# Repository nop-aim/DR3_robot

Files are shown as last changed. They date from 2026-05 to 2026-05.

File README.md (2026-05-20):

# 🦾 Robot DR3 — Tài Liệu Dự Án

> **Môn học:** Thực Tập Kỹ Thuật Robot  
> **GVHD:** PGS.TS Đặng Xuân Ba  
> **Sinh viên thực hiện:**
> - Nguyễn Ngọc Hiển — 22151079  
> - Hoàng Thái Bảo — 22151051  
> - Nguyễn Thị Tuyết Mai — 22151112  
> - Phạm Văn Hoàng Quân — 22151142  

---

## 📸 Hình Ảnh Sản Phẩm

| Bản vẽ 3D (SolidWorks) | Hoàn thành |
|:---:|:---:|
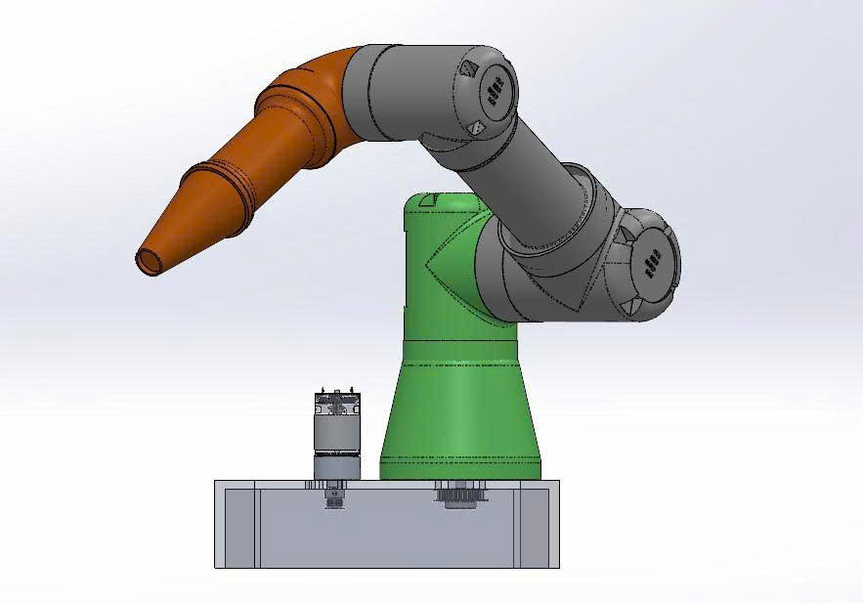
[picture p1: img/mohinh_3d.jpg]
3D Model
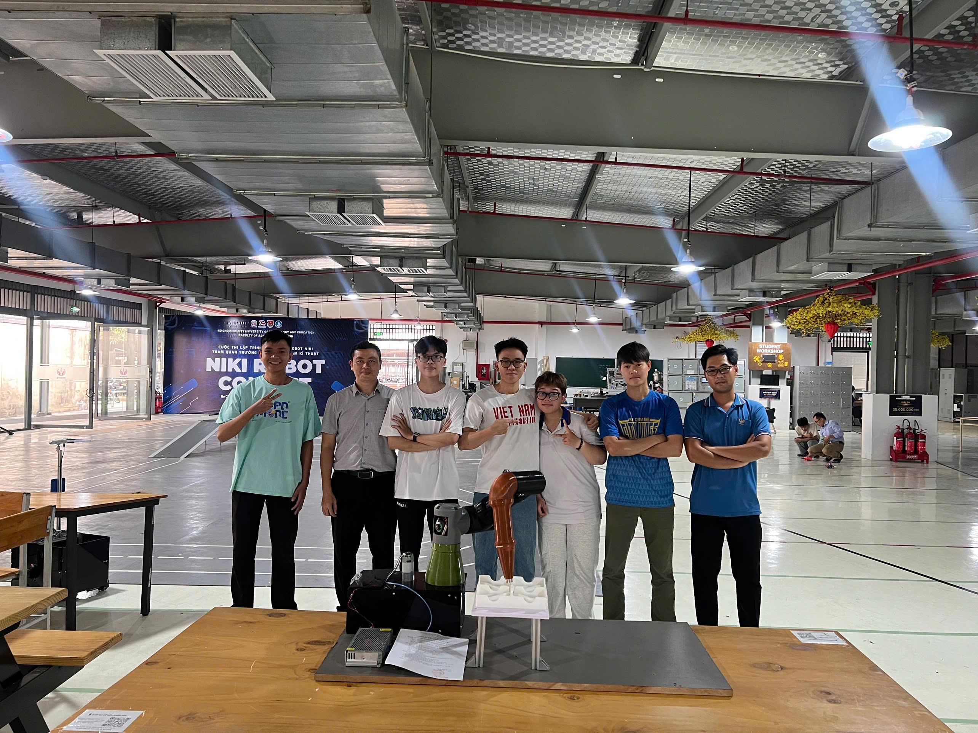
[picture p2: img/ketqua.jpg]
Team photo
|  |  |
| Robot 3-DOF: Base xanh + 2 link xám + EE cam | Nhóm cùng robot hoàn chỉnh|

---

## 📐 Thông Số Kỹ Thuật

| Thông số | Giá trị |
|---|---|
| Số bậc tự do | 3 (q1, q2, q3) |
| L1 — chiều cao từ base đến khớp 1 | 322 mm (142 + 180) |
| L2 — chiều dài link 2 | 275 mm |
| L3 — chiều dài link 3 / EE offset | 280 mm |
| d1 — offset ngang khớp 2 | 135 mm |
| d2 — offset ngang khớp 3 | 115 mm |
| Vi điều khiển | Arduino Mega 2560 |
| Baudrate PC ↔ Arduino | **115200** |
| Encoder M1 (khớp 1) | 16 PPR × 270 × (60/20) × 4 = **51840 xung/vòng** |
| Encoder M2 (khớp 2) | 16 PPR × 506 × 4 = **32384 xung/vòng** |
| Encoder M3 (khớp 3) | 11 PPR × 90 × 4 = **3960 xung/vòng** |
| Tọa độ lỗ thả (HOLE) | X=235, Y=−218, Z=240 mm |

---

## 🗂 Cấu Trúc Thư Mục

```
robot_dr3/
│
├── server_ui.py                  ← Entry point — khởi động toàn hệ thống
│
├── gui/
│   └── control_panel.py          ← Giao diện tkinter (StartPage + ControlPanel)
│
├── robot_controller/
│   └── robot_controller.py       ← Logic điều khiển, chạy trong thread riêng
│
├── kinematic/
│   ├── __init__.py
│   ├── DH_modify.py              ← Ma trận DH cải tiến
│   ├── forward_kinematics.py     ← Động học thuận
│   └── inv_kinematic.py          ← Động học nghịch (4 nghiệm)
│
├── com/
│   └── connect.py                ← Giao tiếp Serial (thread + queue)
│
├── arduino/
│   └── main.ino                  ← Firmware Arduino Mega
│
├── test_kinematic.py             ← Script test IK/FK qua terminal
└── requirements.txt
```

> ⚠️ **Quan trọng:** Import trong code dùng đường dẫn `from kinematic import ...` và `from com import connect as cn`. Phải **chạy từ thư mục gốc** `robot_dr3/`.

---

## ⚙️ Cài Đặt Môi Trường

### 1. Cài Python 3.9+

Tải tại [python.org](https://www.python.org/downloads/).  
Khi cài trên Windows: **tick "Add Python to PATH"**.

```bash
python --version   # Kiểm tra: Python 3.9.x trở lên
```

### 2. Tạo môi trường ảo (khuyến nghị)

```bash
python -m venv venv

# Windows
venv\Scripts\activate

# Linux / macOS
source venv/bin/activate
```

### 3. Cài thư viện

```bash
pip install numpy pyserial
```

`requirements.txt`:
```
numpy>=1.21.0
pyserial>=3.5
```

```bash
pip install -r requirements.txt
```

### 4. Cài Arduino IDE + Thư Viện Encoder

1. Tải [Arduino IDE 2.x](https://www.arduino.cc/en/software)
2. Mở **Library Manager** (`Ctrl+Shift+I`)
3. Tìm và cài: **`Encoder` by Paul Stoffregen**
4. Cắm Arduino Mega vào USB
5. Chọn **Board**: `Arduino Mega or Mega 2560`
6. Chọn đúng **Port** (ví dụ `COM6`)
7. Upload `arduino/main.ino`

---

## 🔌 Pinout Arduino Mega 2560

| Thành phần | Chân |
|---|---|
| Motor 1 — IN1 / IN2 / ENA | 14 / 15 / 4 |
| Encoder 1 — A / B | 3 (INT0) / 2 (INT1) |
| Motor 2 — IN1 / IN2 / ENA | 17 / 12 / 5 |
| Encoder 2 — A / B | 21 (INT5) / 20 (INT4) |
| Motor 3 — IN1 / IN2 / ENA | 11 / 10 / 9 |
| Encoder 3 — A / B | 18 (INT3) / 19 (INT2) |
| Van hút (Solenoid) — ENA | 7 |
| Cảm biến homing 1 / 2 / 3 | 46 / 44 / 42 |

---

## 🚀 Chạy Chương Trình

```bash
# Từ thư mục gốc robot_dr3/
python server_ui.py
```

Giao diện khởi động qua 2 bước:

**Màn hình StartPage** — hiện thông tin nhóm, nhấn **START** để vào bảng điều khiển.
<p align="center">
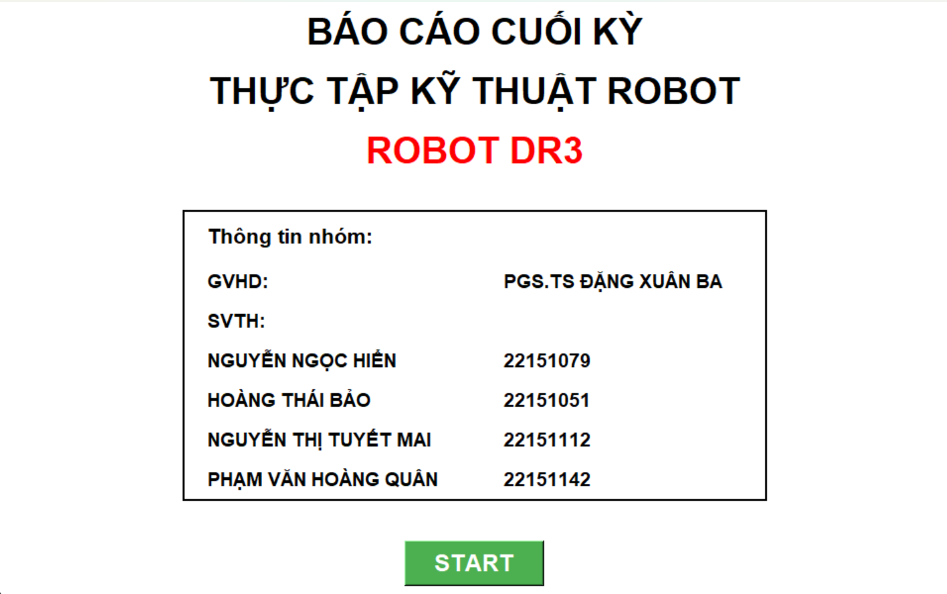
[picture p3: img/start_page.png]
  
</p>

**ControlPanel** — các nút điều khiển:
<p align="center">
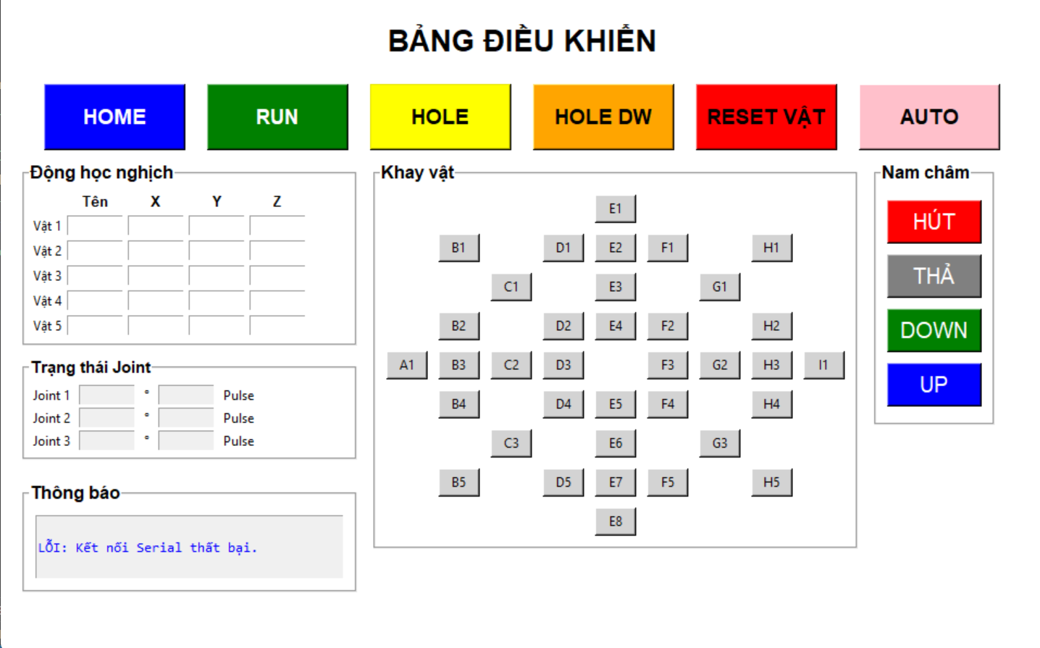
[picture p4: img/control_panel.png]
  
</p>

| Nút | Chức năng |
|---|---|
| **HOME** | Về vị trí gốc (chạy homing sequence) |
| **RUN** | Di chuyển tới tọa độ vật đang chọn (bay trên Z=240) |
| **HOLE** | Di chuyển tới vị trí lỗ thả (235, −218, 240) |
| **HOLE DW** | Hạ xuống lỗ thả (Z = 240 − 20 = 220) |
| **RESET VẬT** | Xóa toàn bộ danh sách vật đã chọn |
| **AUTO** | Tự động hút & thả toàn bộ vật đã chọn (tối đa 5) |

**Chọn vật từ khay:** Click vào ô lưới (A1, B1, C2 …) → tọa độ tự điền vào bảng "Vật 1 → 5".

---

## 🏗 Kiến Trúc Hệ Thống

```
┌──────────────────────────────────────────────────────────────┐
│                        server_ui.py                          │
│                                                              │
│   Main Thread (GUI)              Logic Thread (Robot)        │
│   ─────────────────              ──────────────────────      │
│                                                              │
│   StartPage (tkinter)            RobotController.run()       │
│        │                              │                      │
│        ▼                              ▼                      │
│   ControlPanel ──── cmd_queue ──► process_command()          │
│        ▲                │              │                     │
│        │                │         IK → Serial → wait DONE    │
│        └──── res_queue ◄┘              │                     │
│                                        ▼                     │
│                              connect.py (COM6, 115200)       │
│                                   │            ▲             │
│                              send_serial   reader_thread     │
│                                   │            │             │
│                                   ▼            │             │
│                            Arduino Mega 2560                 │
│                            (PID + S-Curve + Homing)          │
└──────────────────────────────────────────────────────────────┘
```

### Luồng Queue giữa GUI ↔ RobotController

```
GUI gửi lệnh:
  cmd_queue.put( ("SET",  (px, py, pz, idx)) )
  cmd_queue.put( ("HOLE", (px, py, pz, idx)) )
  cmd_queue.put( ("HOME", None) )
  cmd_queue.put( ("HUT",  None) )
  cmd_queue.put( ("THA",  None) )
  cmd_queue.put( ("QUIT", None) )

Robot phản hồi:
  res_queue.put( ("DONE",       (cmd_type, idx, angles)) )
  res_queue.put( ("IK_SUCCESS", (angles, pulses, idx))   )
  res_queue.put( ("IK_FAILED",  None)                    )
  res_queue.put( ("ERROR",      "message")               )
  res_queue.put( ("LOG",        "message")               )
```

ControlPanel gọi `self.after(100, self.check_logic_response)` để poll `res_queue` mỗi 100 ms — **không block GUI thread**.

---

## 🧮 Thuật Toán Động Học

### Ma Trận DH Cải Tiến (`DH_modify.py`)

$$
T_{i-1,i} =
\begin{bmatrix}
\cos\theta & -\sin\theta & 0 & a \\
\sin\theta\cos\alpha & \cos\theta\cos\alpha & -\sin\alpha & -\sin\alpha d \\
\sin\theta\sin\alpha & \cos\theta\sin\alpha & \cos\alpha & \cos\alpha d \\
0 & 0 & 0 & 1
\end{bmatrix}
$$

### Bảng Tham Số DH Robot DR3

$$
\begin{array}{|c|c|c|c|c|}
\hline
\textbf{Khớp} & \boldsymbol{\alpha\ (^\circ)} & \mathbf{a\ (mm)} & \boldsymbol{\theta} & \mathbf{d\ (mm)} \\
\hline
0 \rightarrow 1 & 0 & 0 & q_1 & L_1 = 322 \\
\hline
1 \rightarrow 2 & 90 & 0 & q_2 + 90^\circ & -d_1 = -135 \\
\hline
2 \rightarrow 3 & 0 & L_2 = 275 & q_3 & d_2 = 115 \\
\hline
3 \rightarrow EE & 0 & L_3 = 280 & 0 & 0 \\
\hline
\end{array}
$$

Động học thuận:
```python
T0_EE = T01 @ T12 @ T23 @ T3EE   # Ma trận 4×4
(Px, Py, Pz) = T0_EE[:3, 3]
```

### Động Học Nghịch (`inv_kinematic.py`)

```
Bước 1 — Tính w1 (2 ứng viên):
  r = √(Px² + Py²)
  α = atan2(Px, −Py)
  t = (d2 − d1) / r
  w1 = atan2(±√(1−t²), t) + α

Bước 2 — Với mỗi w1, tính w3 (2 nhánh ±s3):
  A = Px·cos(w1) + Py·sin(w1)
  B = Pz − L1
  c3 = (A² + B² − L2² − L3²) / (2·L2·L3)
  w3 = atan2(±√(1−c3²), c3)

Bước 3 — Tính w2:
  w2 = atan2(B, A) − atan2(L2 + L3·cos(w3), −L3·sin(w3))

→ Tối đa 4 nghiệm, loại trùng rồi chọn nghiệm có cả 3 góc ≤ 0
  (cấu hình elbow-up, phù hợp không gian làm việc thực tế)
```

---

## 🎮 Firmware Arduino — Điều Khiển PID Cascade

### Hai Vòng Lặp Độc Lập

| Vòng | Tần số | Nhiệm vụ |
|---|---|---|
| **Outer** — Position PID | 50 Hz (20 ms) | Sai số vị trí → lệnh vận tốc mong muốn |
| **Inner** — Velocity PID | 200 Hz (5 ms) | Bám vận tốc đặt → xuất PWM động cơ |

### Hệ Số PID (đã tinh chỉnh thực nghiệm)

| | Kp_pos | Ki_pos | Kd_pos | Kp_vel | Ki_vel | Kd_vel |
|---|---|---|---|---|---|---|
| Khớp 1 | 8.5 | 0.0 | 0.80 | 6.3 | 0.2 | 0.0 |
| Khớp 2 | 7.5 | 0.0 | 0.10 | 6.8 | 0.1 | 0.0 |
| Khớp 3 | 7.5 | 0.0 | 0.15 | 8.5 | 1.8 | 0.0 |

Ngoài ra có **Feedforward trọng trường** (`Kgrav`) và **Feedforward vận tốc/gia tốc** (`Kff_v`, `Kff_a`) cho khớp 2 và 3.

### Quỹ Đạo Quintic S-Curve

Hệ số đa thức bậc 5 đảm bảo vận tốc và gia tốc bằng 0 tại đầu/cuối:

```
p(t) = a₀ + a₁t + a₂t² + a₃t³ + a₄t⁴ + a₅t⁵

a₃ = 10·Δp / T³
a₄ = −15·Δp / T⁴
a₅ =   6·Δp / T⁵

T = max(2·|Δp| / MAX_VEL, MIN_TRAJ_TIME)
  với MAX_VELOCITY = 5000 xung/s, MIN_TRAJ_TIME = 1.5 s
```

### Tiêu Chí Kết Thúc Lệnh

Arduino chỉ gửi `"ALL DONE"` + `"DONE"` khi **đồng thời**:

- Quỹ đạo S-curve đã hoàn tất (`traj_active = false`)
- Sai số vị trí còn lại ≤ 3–7 xung
- Vận tốc hiện tại < 0.1–0.2 xung/ms
- Duy trì điều kiện trên liên tục **500 chu kỳ** (~2.5 s tại 200 Hz)
- Robot đã thực sự di chuyển (`has_moved = true`, encoder lệch > 5 xung)

---

## 📡 Giao Thức Lệnh Serial

| Lệnh | Cú pháp gửi | Arduino phản hồi |
|---|---|---|
| Di chuyển đến góc | `SET q1 q2 q3` (độ, float) | `DONE` và `ALL DONE` |
| Về HOME (homing) | `HOME` | `HOME DONE` |
| Bật van hút | `HUT` | `HUT DONE` |
| Tắt van hút | `THA` | `THA DONE` |

---

## 🔄 Luồng AUTO 

Luồng này sẽ gắp 5 vật liên tiếp, khi nhấn **AUTO**, `ControlPanel` tạo chuỗi lệnh cho mỗi vật như sau:

```
Cho mỗi vật i (i = 1..5):
  1. SET → (HOLE_X, HOLE_Y, HOLE_Z)      # Đến trên lỗ
  2. SET → (x_i, y_i, HOLE_Z)            # Đến trên vật (bay cao)
  3. HUT                                  # Bật hút
  4. SET → (x_i, y_i, z_i)              # Hạ xuống vật
  5. SET → (x_i, y_i, HOLE_Z)            # Nâng lên
  6. SET → (HOLE_X, HOLE_Y, HOLE_Z)      # Đến trên lỗ
  7. SET → (HOLE_X, HOLE_Y, HOLE_Z−20)   # Hạ vào lỗ
  8. THA                                  # Thả vật
```

Mỗi lệnh chỉ được gửi sau khi nhận `DONE` từ lệnh trước (xử lý trong `check_logic_response` với `self.after()`), tránh blocking GUI.

---

## 🧪 Test Động Học Qua Terminal

Dùng `test_kinematic.py` để kiểm tra IK/FK và giao tiếp Serial **không cần GUI**:

```bash
python test_kinematic.py
```

Nhập lệnh:
```
Nhập lệnh: 200 -150 300       # Nhập tọa độ Px Py Pz (mm)
Nhập lệnh: HOME
Nhập lệnh: HUT
Nhập lệnh: THA
Nhập lệnh: q                  # Thoát
```

Sau mỗi lệnh SET thành công, chương trình kiểm chứng lại bằng FK và in ra tọa độ Cartesian kết quả.

---

## ❗ Xử Lý Lỗi Thường Gặp

| Lỗi | Nguyên nhân | Giải pháp |
|---|---|---|
| `Không mở được serial` | Sai cổng hoặc chưa cắm USB | Sửa `SERIAL_PORT` trong `com/connect.py` |
| `ModuleNotFoundError: kinematic` | Chạy từ thư mục con | Chạy từ thư mục gốc `robot_dr3/` |
| `IK_FAILED` / không tìm được nghiệm | Tọa độ ngoài vùng làm việc | Kiểm tra (Px, Py, Pz) hợp lệ |
| Robot không gửi `DONE` | Queue bị nghẽn / timeout | Restart Python, kiểm tra baudrate = 115200 |
| Robot rung lắc | Kp quá cao | Giảm `Kp_pos` trong `main.ino` |
| Encoder sai chiều | Đảo A/B | Hoán đổi `ENC_A ↔ ENC_B` trong khai báo `Encoder enc_lib(B, A)` |
| HOME không dừng | Cảm biến homing không nhận | Kiểm tra chân 42 / 44 / 46, dây nối `INPUT_PULLUP` |

---

## 📄 Cấu Hình Nhanh

Chỉ cần sửa **một chỗ duy nhất** để thay đổi cổng Serial:

```python
# com/connect.py
SERIAL_PORT = "COM6"      # Windows: COM3, COM4, ...
# SERIAL_PORT = "/dev/ttyUSB0"    # Linux
# SERIAL_PORT = "/dev/tty.usbmodem14101"  # macOS
BAUDRATE = 115200
```

---

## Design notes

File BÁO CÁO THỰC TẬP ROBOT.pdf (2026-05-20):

BỘ GIÁO DỤC VÀ ĐÀO TẠO

TRƯỜNG ĐẠI HỌC SƯ PHẠM KỸ THUẬT TP.HCM

KHOA ĐIỆN – ĐIỆN TỬ

BỘ MÔN TỰ ĐỘNG ĐIỀU KHIỂN

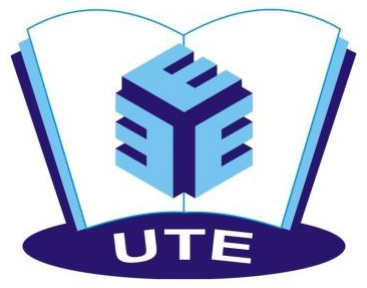
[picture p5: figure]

## BÁO CÁO CUỐI KỲ

## THỰC TẬP ROBOT

## CÁNH TAY ROBOT DR3 BA BẬC TỰ DO

GVHD: PGS.TS. Đặng Xuân Ba
SVTH: Nguyễn Ngọc Hiển | 22151079
Hoàng Thái Bảo | 22151051
Nguyễn Thị Tuyết Mai 22151112

Phạm Văn Hoàng Quân 22151142

TP. Hồ Chí Minh, tháng 12 năm 2025

i

LỜI CẢM ƠN

Chúng em xin chân thành gửi lời cảm ơn đến thầy Đặng Xuân Ba – người đã tận

tình hướng dẫn, định hướng và hỗ trợ chúng em trong suốt quá trình thực hiện đề tài. Sự

tận tâm và kiến thức chuyên môn sâu rộng của thầy không chỉ giúp em hoàn thành tốt

nội dung học thuật, mà còn truyền cảm hứng để em tiếp tục theo đuổi lĩnh vực điều

khiển và tự động hoá một cách nghiêm túc và bài bản.

Dù vẫn còn những thiếu sót nhất định, nhưng em hy vọng báo cáo này sẽ phản ánh

được nỗ lực học tập và nghiêm túc nghiên cứu của nhóm trong suốt học kỳ vừa qua.

ii

MỤC LỤC

iii

iv

DANH MỤC BẢNG BIỂU

v

DANH MỤC HÌNH ẢNH

CHƯƠNG 1. TỔNG QUAN

### 1.1. Đặt vấn đề

Cách mạng công nghiệp 4.0 đã thúc đẩy mạnh mẽ việc ứng dụng robot trong sản

xuất và đào tạo kỹ thuật. Robot công nghiệp ngày càng được sử dụng rộng rãi nhằm tự

động hóa các công việc lặp đi lặp lại, yêu cầu độ chính xác cao và nâng cao năng suất

lao động. Trong bối cảnh đó, việc tiếp cận và thực hành với các mô hình robot cơ bản

trong quá trình học tập có ý nghĩa quan trọng, giúp sinh viên nắm vững kiến thức nền

tảng về robot và điều khiển tự động.

Trong môn Thực tập Robot, robot cánh tay 3 bậc tự do (3 DOF) được sử dụng làm mô hình thực hành điển hình. Với cấu trúc đơn giản nhưng đầy đủ chức năng cơ bản,

robot 3 DOF có khả năng thực hiện các bài toán gắp và di chuyển vật thể trong không

gian, cụ thể là bài toán gắp bi. Thông qua bài toán này, sinh viên có thể hiểu rõ nguyên

lý chuyển động của các khớp, mối quan hệ giữa chuyển động khớp và vị trí đầu công

tác, cũng như cách phối hợp các trục để hoàn thành nhiệm vụ.

Để điều khiển chuyển động của robot, phương pháp điều khiển PID truyền thống

được áp dụng cho từng khớp. PID có ưu điểm là dễ cài đặt, dễ hiệu chỉnh và phù hợp

với các hệ thống robot đơn giản trong môi trường thực tập. Quá trình dò và điều chỉnh

các thông số PID giúp robot đạt được độ chính xác và ổn định cần thiết khi thực hiện

thao tác gắp bi.

Đề tài thực tập “Cánh tay robot DR3 ba bậc tự do” giúp sinh viên vận dụng kiến

thức lý thuyết vào thực tế, rèn luyện kỹ năng lập trình, điều khiển robot và đánh giá hiệu

quả vận hành của hệ thống, tạo nền tảng cho các môn học và ứng dụng nâng cao sau

này.

### 1.2. Mục tiêu

❖ Mục tiêu chung

Đề tài nhằm thiết kế và triển khai thành công mô hình robot cánh tay phục vụ học

tập và thực hành, có khả năng thực hiện bài toán gắp bi một cách ổn định và chính xác.

Thông qua quá trình thiết kế cơ khí, lắp ráp phần cứng và lập trình điều khiển, đề tài giúp sinh viên hiểu rõ nguyên lý hoạt động của robot công nghiệp và ứng dụng điều

khiển PID trong thực tế.

❖ Mục tiêu cụ thể

- Thiết kế mô hình robot cánh tay bằng phần mềm SolidWorks, bao gồm đầy đủ

các khớp chuyển động, tay gắp và kết cấu cơ khí phù hợp với yêu cầu gắp bi.

- Thực hiện lắp ráp và đi dây điện cho từng khớp động cơ, đảm bảo kết nối đúng

kỹ thuật, an toàn và hoạt động ổn định trong quá trình vận hành robot.

- Xây dựng và triển khai bộ điều khiển PID cho các động cơ tại các khớp, thông

qua việc dò và hiệu chỉnh tham số để đạt được chuyển động mượt và chính xác.

- Kiểm tra và đánh giá khả năng hoạt động của robot thông qua bài toán gắp và di

chuyển bi, đảm bảo robot thực hiện đúng quỹ đạo và yêu cầu đề ra.

- Góp phần củng cố kiến thức về robot, điều khiển tự động và kỹ năng thực hành,

làm nền tảng cho các môn học chuyên ngành và ứng dụng thực tế sau này.

### 1.3. Giới hạn đề tài

Giới hạn của đề tài được xác định nhằm đảm bảo phù hợp với mục tiêu học tập,

thời gian thực hiện và nguồn lực triển khai trong khuôn khổ môn Thực tập Robot. Cụ

thể, đề tài chỉ tập trung vào mô hình robot cánh tay có số bậc tự do hạn chế (robot 3 bậc

tự do) phục vụ cho bài toán gắp và di chuyển bi trong không gian làm việc đơn giản.

Các chuyển động của robot được xem xét chủ yếu ở mức cơ bản, không yêu cầu độ

chính xác cao như trong các ứng dụng công nghiệp phức tạp.

Về mặt điều khiển, đề tài chỉ sử dụng phương pháp điều khiển PID truyền thống,

được cài đặt trực tiếp trên vi điều khiển Arduino để điều khiển các động cơ tại các khớp

robot. Các phương pháp điều khiển nâng cao như điều khiển thích nghi, điều khiển tối

ưu, điều khiển mờ, hay các thuật toán học máy không được xem xét trong phạm vi đề

tài. Việc hiệu chỉnh PID được thực hiện theo phương pháp thử – sai (tuning thủ công) nhằm phục vụ mục tiêu học tập và thực hành.

Về mặt phần mềm, hệ thống được lập trình và giao tiếp thông qua Arduino và

Python, trong đó Arduino đảm nhiệm vai trò điều khiển phần cứng và Python được sử dụng để giao tiếp, gửi lệnh và quan sát trạng thái hoạt động của robot. Đề tài không triển

khai mô phỏng động lực học phức tạp trên các môi trường như MATLAB/Simulink, cũng không xây dựng mô hình toán học chi tiết của robot.

Ngoài ra, đề tài chưa xét đến các yếu tố ảnh hưởng phức tạp trong thực tế như ma

sát tại khớp, độ đàn hồi cơ khí, rung động, sai số cảm biến, nhiễu tín hiệu hay sự thay

đổi tải trọng trong quá trình gắp vật. Các vấn đề liên quan đến tối ưu hóa năng lượng,

an toàn vận hành nâng cao, hoặc ứng dụng robot trong môi trường công nghiệp thực tế

cũng không nằm trong phạm vi nghiên cứu của đề tài.

Do đó, kết quả đạt được chủ yếu mang tính thực hành và minh họa nguyên lý,

nhằm giúp sinh viên hiểu rõ cấu trúc, nguyên lý hoạt động và cách điều khiển cơ bản

của robot cánh tay, làm nền tảng cho các nghiên cứu và ứng dụng nâng cao trong tương

lai.

### 1.4. Nội dung nghiên cứu

Đề tài “Cánh tay robot DR3 ba bậc tự do” được xây dựng với các nội dung chính

sau:

− Chương 1: Tổng quan

− Chương 2: Cơ sở lý thuyết

− Chương 3: Thiết kế hệ thống

− Chương 4: Thiết kế thuật toán cho hệ thống

− Chương 5: Đánh giá trên thực nghiệm
− Chương 6: Kết luận

CHƯƠNG 2. CƠ SỞ LÝ THUYẾT

### 2.1. Tổng quan về Robot DR3

### 2.1.1. Giới thiệu chung

Robot DR3 trong đề tài này là một robot thuộc loại cánh tay máy nối tiếp (serial

manipulator). Đây là cấu trúc robot phổ biến nhất trong công nghiệp, được thiết kế mô

phỏng theo chức năng của cánh tay người. Robot bao gồm một chuỗi các khâu (links)

cứng được kết nối với nhau bằng các khớp (joints) động.

Loại robot này được ứng dụng rộng rãi trong nhiều lĩnh vực như lắp ráp, hàn, sơn,

và đặc biệt là các tác vụ gắp thả vật (pick-and-place) nhờ khả năng di chuyển linh hoạt

trong không gian làm việc của nó.

### 2.1.2. Cấu trúc Robor DR3 3 bậc tự do

Robot có 3 khớp quay chính, tạo nên 3 bậc tự do:

- Khớp 1 (Khớp đế): Cho phép toàn bộ cánh tay quay quanh trục thẳng đứng trên

đế.

- Khớp 2 (Khớp vai): Nâng/hạ cánh tay trên (khâu nối với đế).
- Khớp 3 (Khớp khuỷu): Gập/duỗi cánh tay dưới (khâu xa đế hơn).

Sự kết hợp chuyển động của 3 khớp này cho phép điểm cuối của robot (end-

effector) di chuyển đến các vị trí khác nhau trong không gian làm việc 3D.

### 2.1.3. Ưu nhược điểmm khi sử dụng Robot DR3 để gắp vật

❖ Ưu điểm:

- Không gian làm việc lớn: Robot có thể vươn tới các điểm xa và bao quát một

vùng làm việc rộng lớn xung quanh đế.

- Tính linh hoạt cao: Khả năng tiếp cận một vị trí từ nhiều hướng khác nhau, giúp

dễ dàng tránh vật cản.

- Cấu trúc đơn giản, dễ hiểu: Nguyên lý hoạt động và tính toán động học tương

đối trực quan, dễ tiếp cận cho mục đích học tập và nghiên cứu.

❖ Nhược điểm:

- Độ cứng vững thấp: Do cấu trúc dạng chuỗi hở, tải trọng và sai số bị tích lũy từ

gốc đến ngọn, làm giảm độ cứng vững, đặc biệt khi vươn xa.

- Tải trọng hạn chế: Các khớp phía gốc (như khớp vai) phải chịu mô-men lớn do

trọng lượng của toàn bộ các khâu phía sau và vật gắp.

- Tốc độ và gia tốc thấp hơn: Robot có khối lượng phần động lớn hơn, dẫn đến

quán tính lớn, làm hạn chế tốc độ và gia tốc tối đa.

### 2.2. Bộ điều khiển PID

Trong lĩnh vực điều khiển, bộ điều khiển PID (Proportional-Integral-Derivative)

là thuật toán phổ biến nhất nhờ tính hiệu quả và khả năng ứng dụng rộng rãi. Bộ điều

khiển này tính toán giá trị sai số $e(t)$ thông qua hiệu số giữa giá trị đo được (phản hồi)

và giá trị đặt mong muốn, từ đó điều chỉnh tín hiệu đầu ra để giảm thiểu sai số, giúp hệ

thống đạt được trạng thái ổn định.

Công thức tổng quát của bộ điều khiển PID:

0

( ) | ( ) | ( ) p | i | d

t
de u t | K e t | K e t dt K
dt
= | + | + ò
(2.1)

Trong đó:

- u(t): Tín hiệu điều khiển theo thời gian t.
- e(t): Sai số hệ thống theo thời gian t.
- Kp

, Ki và Kd

: Lần lượt là các hệ số tỉ lệ, tích phân và đạo hàm.

Việc hiệu chỉnh các thông số này sẽ thay đổi trực tiếp đặc tính của hệ thống:

- Kp

: Tác động đến tốc độ đáp ứng và sai số xác lập.

- Ki

: Giúp triệt tiêu sai số xác lập nhưng có thể gây vọt lố.

- Kd

: Giúp cải thiện độ ổn định và giảm độ vọt lố của hệ thống.

Bộ điều khiển PID nhận tín hiệu sai số từ cảm biến để tính toán và điều chế xung

PWM cấp cho các động cơ DC. Quá trình này diễn ra liên tục, đảm bảo các khớp của

cánh tay robot chuyển động chính xác đến vị trí mong muốn với độ sai lệch thấp nhất.

CHƯƠNG 3. THIẾT KẾ HỆ THỐNG

### 3.1. Giới thiệu tổng quan về hệ thống

### 3.1.1. Sơ đồ tổng quan hệ thống

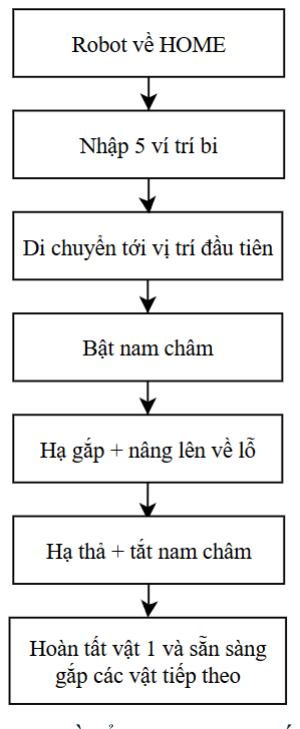
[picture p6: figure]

Hình 3.1. Sơ đồ tổng quan hệ thống gắp bi

### 3.1.2. Tính toán động học thuận, động học nghịch

3.1.2.1. Tính động học thuận cho Robot

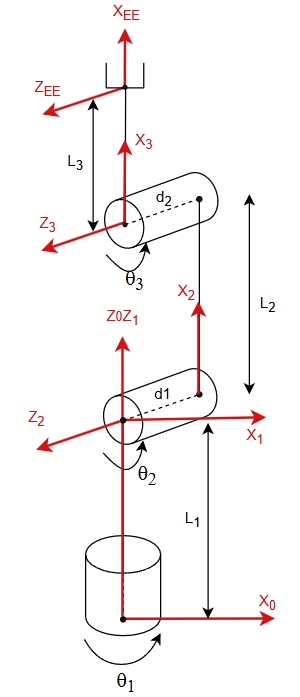
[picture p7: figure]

Hình 3.2. Đặt trục robot

❖ Bảng DH:

Bảng 3.1. Bảng DH

i | di | θi | ai-1 | αi-1
1 | l1 | q1 | 0 | 0
2 | -d1 | q2 + 90 | 0 | 90
3 | d2 | q3 | l2 | 0
4 | 0 | 0 | l3 | 0

❖ Tính toán các ma trận chuyển đổi:

Chuyển từ hệ {1} sang {0}:

| 1 | 1
0 | 1 | 1
1
1
| | 0 | 0
| | 0 | 0
0 | 0 | 1
0 | 0 | 0 | 1
c | s
s | c
T
l
é | ù −
ê | | ú
=
ê | | ú
ê | | ú
ê | ú ë | û

(3.1)

Chuyển từ hệ {2} sang {1}:

2 | 2
1 | 1
2
2 | 2
| | 0 | 0
0 | 0 | 1
| | 0 | 0
0 | 0 | 0 | 1
s | c
| | | d
T
c | s
é | ù − | −
ê | | ú −
=
ê | | ú
ê | | ú −
ê | ú ë | û

(3.2)

Chuyển từ hệ {3} sang {2}:

3 | 3 | 2
2 | 3 | 3
3
2

0
| | 0 | 0
0 | 0 | 1
0 | 0 | 0 | 1
c | s | l
s | c
T
| | d
é | ù −
ê | | ú
ê | ú =
ê | | ú
ê | ú ë | û

(3.3)

Chuyển từ hệ {EE} sang {3}:

3

3

1 | 0 | 0
0 | 1 | 0 | 0
0 0 | 1 | 0
0 0 | 0 | 1

EE

l

T

é | | ù
ê | | ú
= ê | | ú
ê | | ú
ê | ú ë | û

(3.4)

Ma trận chuyển đổi từ hệ trục tọa độ {EE} sang hệ trục tọa độ {0}:

1 23 | 1 23 | 1 | 2 1 2 | 3 1 23 | 1 1 | 2 1
0 | 1 23 | 1 23 | 1 | 2 1 2 | 3 1 23 | 1 1 | 2 1
23 | 23 | 1 | 2 2 | 3 23 0
0 | 0 | 0 | 1

EE

c s | c c | s | l c s | l c s | d s | d s
s s | s c | c | l s s | l s s | d c | d c
T
c | s | l | l c | l c
é | ù − | − | − | − | − | +
ê | ú − | − | − | − | − | + | − ê | ú =
ê | ú − | + | + ê | ú ë | û

(3.5)

Từ đó ta tìm được tọa độ điểm cuối của robot {EE} sang hệ trục tọa độ gốc {0}:

2 1 2 | 3 1 23 | 1 1 | 2 1
0
2 1 2 | 3 1 23 | 1 1 | 2 1
1 | 2 2 | 3 23

EE

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

(3.6)

3.1.2.2. Tính động học nghịch cho Robot

Ta có (3.5) tương đương với ma trận chuyển đổi đồng nhất như sau:

11 | 12 | 13
0 | 21 | 22 | 23
4
31 | 32 | 33
0 | 0 | 0 | 1

x

y

z

R | R | R | P
R | R | R | P
T
R | R | R | P
é | | | ù
ê | | | ú
ê | ú =
ê | | | ú
ê | ú ê | ú ë | û

(3.7)

Với:

P | l c s | l c s | d s | d s x
= − | − | − | + 2 1 2 | 3 1 23 | 1 1 | 2 1

(3.8)

P | l s s | l s s | d c | d c y
= − | − | + | − 2 1 2 | 3 1 23 | 1 1 | 2 1
(3.9)
P | l | l c | l c z
= + | + 1 | 2 2 | 3 23

(3.10)

- Tìm q1:

Ta lấy (3.8) nhân s1 và (3.9) nhân c1 ta được phương trình sau:

| | | 2 | 2
1 | 2 1 2 1 | 3 1 23 1 | 1 1 | 2 1
| | | 2 | 2
1 | 2 1 2 1 | 3 1 23 1 | 1 1 | 2 1

x

y

P s | l c s s | l c s s | d s | d s
P c | l s s c | l s s c | d c | d c
ìï | = − | − | − | +
í
ï | = − | − | + | − î

(3.11)

Trừ (3.11) theo vế ta thu được:

P s | P c | d | d x | y 1 | 1 | 2 | 1
− | = | −
(3.12)

Đưa công thức (3.12) về dạng
1 | 1 asin q | b | q | d ( ) | cos( ) + | = , khi đó:

2 | 2 | 2 | 2
tan 2 | , a | b
a
a | b | a | b

α

æ | ö
= | ç | ÷ è | ø + | +
(3.13)

Ta tìm được 2 nghiệm θ1 như sau:

2

1 | 2 | 2 | 2 | 2

2

1 | 2 | 2 | 2 | 2
tan 2 | 1 | ,
tan 2 | 1 | ,
d | | d
q | a
a | b | a | b
| d | | d
q | a
a | b | a | b

α

α

é | æ | ö ê = | − | + ç | ÷ ê
ç | ÷ è | ø ⁺ | +
ê
ê | æ | ö
ê
′ = | − | − | + ç | ÷
ê
ç | ÷ è | ø ⁺ | + ë

(3.14)

- Tìm θ3:

Ta lấy (3.8) nhân c1 và (3.9) nhân s1 ta được phương trình sau:

| 2 | | 2
1 | 2 1 | 2 | 3 1 | 23 | 1 1 1 | 2 1 1
| 2 | | 2
1 | 2 1 | 2 | 3 1 | 23 | 1 1 1 | 2 1 1

x

y

P c | l c s | l c s | d s c | d s c
P s | l s s | l s s | d c s | d c s
ìï | = − | − | − | +
í
ï | = − | − | + | − î

(3.15)

Cộng (3.15) theo vế ta thu được:

P c | P s | l s | l s x | y 1 | 1 | 2 2 | 3 23 + | = − | −
(3.16)

Kết hợp phương trình (3.10) và (3.16) ta được hệ phương trình sau:

1 | 1 | 2 2 | 3 23
1 | 2 2 | 3 23
x | y

z

P c | P s | l s | l s
P l | l c | l c
ìï | + | = − | −
í
ïî − = +

(3.17)

Đặt
1 | 1 | 1 , A P c | P s B P l = | + | = | −
x | y | z

, bình phương 2 vế của 2 phương trình trong công

thức (3.17), cộng vế theo vế ta được:

2 | 2 | 2 | 2 | 2 | 2 | 2 | 2 | 2 | 2
2 | 2 | 2 2 3 23 | 3 | 23 | 2 | 2 | 2 2 3 23 | 3 | 23 A | B | l s | l s l s | l s | l c | l c l c | l c + | = | + | + | + | + | + 2 | 2
(3.18)
2 | 2 | 2 | 2
2 | 3 | 2 3 3 A | B | l | l | l l c + | − | − | = 2
(3.19)

Đặt

2 | 2 | 2 | 2 C A | B | l | l = | + | − | − 2 | 3
, ta tìm được c3
:

3
23 2

C
c
ll

=
(3.20)

2
3 | 3 s | c = ± | −1
(3.21)

Ta tìm được 2 nghiệm θ3 như sau:

10 ( | )
( | )
3 | 3 | 3
3 | 3 | 3
tan 2 | ,
tan 2 | ,
q | a | s c
q | a | s c

é=
ê
ê ′
= | − ë

(3.22)

- Tìm θ2:

Từ phương trình (3.17), tách

23 23 cs,
theo công thức lượng giác ta được:
2 2 | 3 | 2 3 | 2 3 | 2 | 3 3 | 2 | 2 | 3 3
2 2 | 3 | 2 3 | 2 3 | 2 | 3 3 | 2 | 2 | 3 3
( | ) | ( | ) | ( | )
( | ) | ( | ) | ( | )
A | l s | l s c | c s | A c | l s | s l | l c
B l c | l c c | s s | B s | l s | c l | l c
ì | ì = − | − | + | = | − | − | + í | í Û
î | î = | + | − | = | − | + | +

(3.23)

Từ phương trình (3.23), ta được:

2 | 2 | 3 3
2
| 33
2 | 2 | 3 3
2
| 33
( | )
( | )
A s l | l c
c
ls
B c l l c
s
ls
ì | + | +
= ï
ï | −
í
− | + ï =
ïî | −

(3.24)

Thay thế s2 và c2
lẫn nhau ở 2 phương trình, ta thu được:
2 | 2 | 3 3
2 | 3 3
| 33
2
33
2 | 2 | 3 3
2 | 3 3
| 33
2
33
( | ) ( | )
( | ) ( | )
B c l | l c A | l | l c
ls
c
ls
A s l | l c B | l | l c
ls
s
ls
ì | − | +
+ | + ï | −
ï =
ï | −
í
+ | + ï | − | + ï | −

ï =
î | −

(3.25)

[ | ]
( | )
[ | ]
( | )
3 3 | 2 | 3 3 | 2 | 2 | 3 3
2 | 2
| | 33
3 3 | 2 | 3 3 | 2 | 2 | 3 3
2 | 2
| | 33
( | ) ( | ) | ( | )
( | ) ( | ) | ( | )
A l s | l | l c | B c l | l c
c
| | ls
B l s | l | l c | A s l | l c
s
| | ls
ì | − | + | + | − | +
ï =
ï
í
− | − | + | + | + ï
=
ï
î

(3.26)

Từ phương trình (3.26), ta tìm được θ2:

q | a | s c 2 | 2 | 2
= tan 2 | , ( | )
(3.27)

Như vậy, ta đã tìm được các góc q thông qua vị trí của End effector

T
P | P | P | P
x | y | z
= é | ù ë | û

( | )
( | )
( | )

2

1 | 2 | 2 2 | 2

2

1 | 2 | 2 2 | 2
2 | 2 | 2
3 | 3 | 3
3 | 3 | 3
tan 2 | , 1
tan 2 | , | 1
tan 2 | ,
tan 2 | ,
tan 2 | ,
d | d
q | a
a | b | a | b
d | d
q | a
a | b | a | b
q | a | s c
q | a | s c
q | a | s c

α

α

ìé | æ | ö ïê = | − | − ç | ÷ ïê | + | +
è | ø ïê
ïê | æ | ö
ïê
′ = | − | − | − ç | ÷
+ | + ïêë | è | ø ï
í =
ï
é= ï
ê ï
ê ′ = − ïë
ï
ï
ï
î

(3.28)

### 3.2. Thiết kế cơ khí

### 3.2.1. Thiết kế 3D trên phần mềm Solidworks

❖ Đế robot

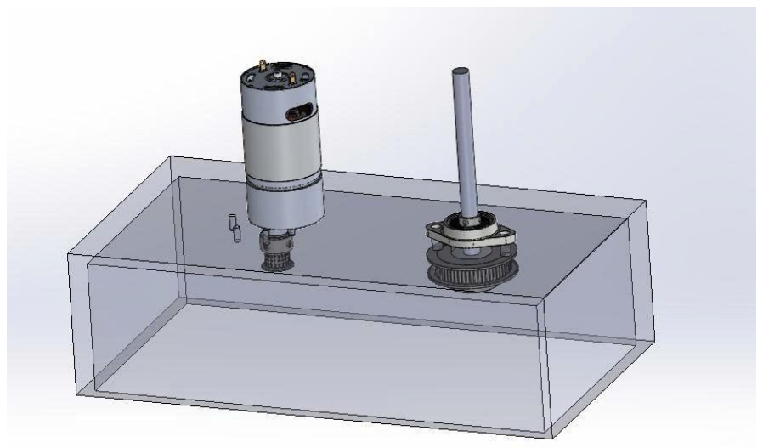
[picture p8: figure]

Hình 3.3. Hình ảnh 3D đế robot

❖ Khớp 1

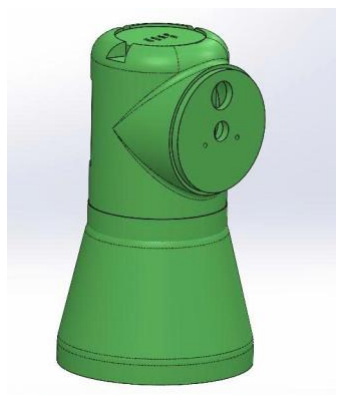
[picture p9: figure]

Hình 3.4. Hình ảnh 3D khớp 1

❖ Khớp 2

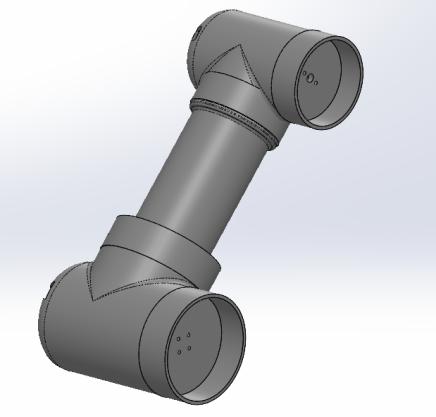
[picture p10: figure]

Hình 3.5. Hình ảnh 3D khớp 2

❖ Khớp 3

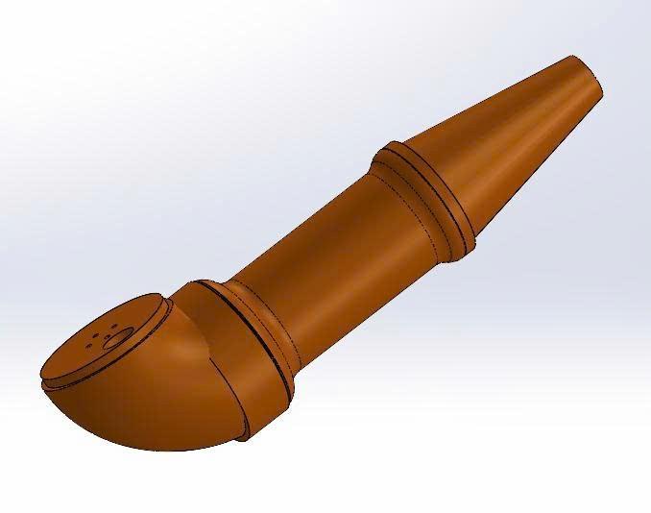
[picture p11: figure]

Hình 3.6. Hình ảnh 3D khớp 3

❖ Bản vẽ Robot hoàn thiện

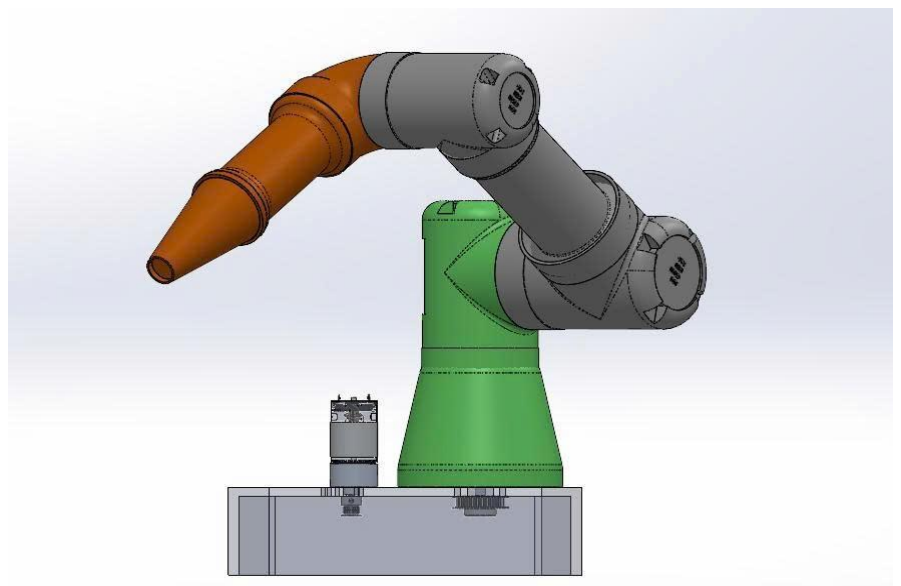
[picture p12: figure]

Hình 3.7. Hình ảnh 3D mô hình robot hoàn thiện

### 3.2.2. Lựa chọn thiết bị phần cứng

❖ Arduino Mega 2560 Pro

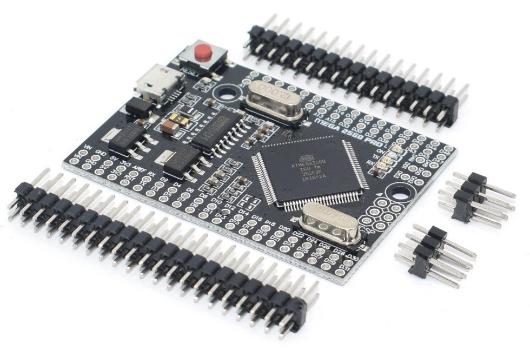
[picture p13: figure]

Hình 3.8. Arduino Mega 2560 Pro

Thông số kỹ thuật:

- Vi điều khiển chính: ATmega2560
- Tốc độ thạch anh: 16Mhz
- Nguồn nuôi mạch:
- 5VDC từ cổng Micro USB.
- Nguồn ngoài từ chân Vin từ 6~9VDC.
- Dòng đầu ra chân 5VDC khi cấp nguồn từ:
- Cổng USB: 500mA
- Chân Vin: 800mA
- Tích hợp IC chuyển nguồn 3.3VDC 800mA.
- Số chân Digital: 54 (hỗ trợ 15 chân PWM)
- Số chân Analog: 16
- Dòng ra tối đa trên GPIO: 20mA
- Dung lượng bộ nhớ Flash: 256 KB, 8 KB used by bootloader.
- SRAM: 8 KB
- EEPROM: 4 KB
- Kích thước: 38 x 55mm

❖ Động cơ Encoder JGB37-545 24V 46RPM

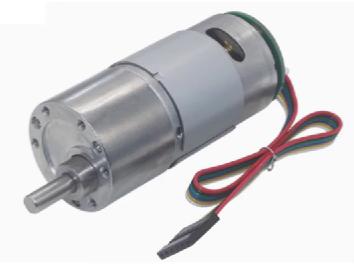
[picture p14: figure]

Hình 3.9. Động cơ Encoder JGB37-545 24V 46RPM

Thông số kĩ thuật:

- Mode: JGB37-545
- Tốc độ quay: 46 rpm
- Mô-men: 3.43 N.m
- Tỉ số truyền: 1:270
- Số xung / vòng: 16
- Điện áp cấp cho động cơ hoạt động: 24VDC
- Đường kính động cơ: 37mm
- Đường kính trục: 6mm

❖ Động cơ Encoder JGB37-545 24V 26RPM

Hình 3.10. Động cơ Encoder JGB37-545 24V 24RPM

Thông số kỹ thuật:

- Mode: JGB37-545
- Tốc độ quay: 24 rpm
- Mô-men: 3.43 N.m
- Tỉ số truyền: 1:506
- Số xung / vòng: 16
- Điện áp cấp cho động cơ hoạt động: 24VDC
- Đường kính động cơ: 37mm
- Đường kính trục: 6mm

❖ Động cơ Encoder JGB37-520 12V 111RPM

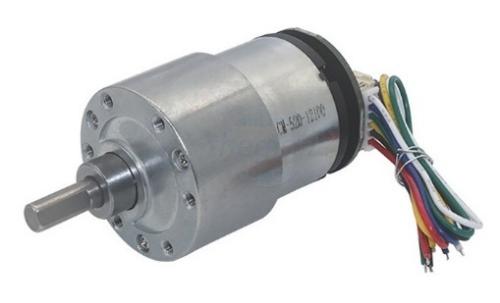
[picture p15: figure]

Hình 3.11. Động cơ Encoder JGB37-520 12V 111RPM

Thông số kĩ thuật:

- Mode: JGB37-520
- Tốc độ quay: 111 rpm
- Mô-men tối đa: 1.47 N.m
- Tỉ số truyền: 1:90
- Số xung / vòng: 11
- Điện áp cấp cho động cơ hoạt động: 12VDC
- Đường kính trục: 6mm
- Đường kính động cơ: 37mm

❖ Module điều khiển động cơ L298N

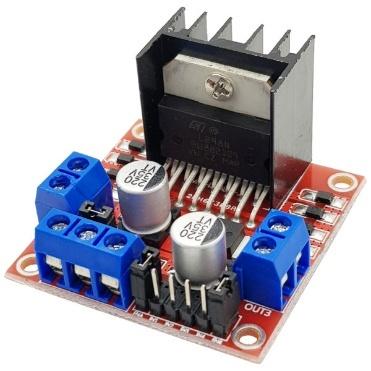
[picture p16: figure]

Hình 3.12. Module điều khiển động cơ L298N

Thông số kỹ thuật:

- Điện áp hoạt động: 5~30VDC
- Công suất tối đa: 25W 1 cầu
- Dòng tối đa cho mỗi cầu H là: 2A
- Mức điện áp logic: Low -0.3V~1.5V, High: 2.3V~Vss
- Kích thước: 43x43x27mm

❖ Module điều khiển động cơ BTS7960 43A

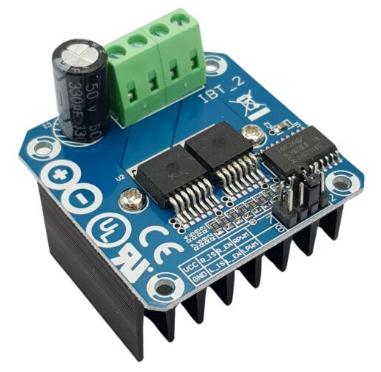
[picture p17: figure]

Hình 3.13. Module điều khiển động cơ BTS7960 43A

Thông số kỹ thuật:

- Nguồn cấp: 6 ~ 27VDC
- Dòng điện tải mạch: 43A (Tải trở) hoặc 15A (Tải cảm)
- Tín hiệu logic điều khiển: 3.3 ~ 5VDC.
- Tần số điều khiển tối đa: 25KHz.
- Bảo vệ quá nhiệt: BTS7960 bảo vệ chống quá nhiệt bằng cảm biến nhiệt tích hợp

bên trong.

- Kích thước: 40 x 50 x12mm.

❖ Mạch giảm áp Buck DC-DC XL4016E1 8A

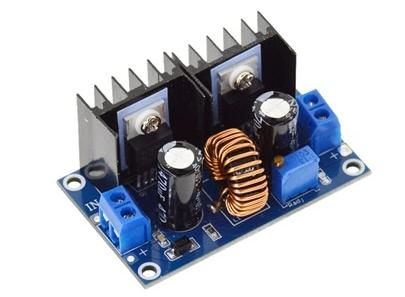
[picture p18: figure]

Hình 3.14. Mạch giảm áp Buck DC-DC XL4016E1 8A

Thông số kĩ thuật:

- Điện áp đầu vào: DC4-40V
- Điện áp đầu ra: DC1.25-36V
- Công suất tối đa: 200W
- Dòng điện ra: max 8A (hoạt động lâu dài, đề nghị 5A)

- Hiệu suất chuyển đổi: 94%
- Kích thước: 61x40x29 mm

❖ Module 1 Relay 12V Kích Mức Cao/Thấp

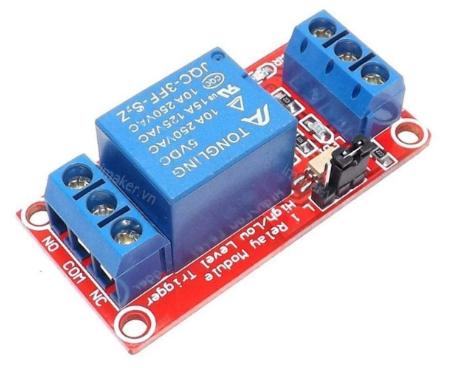
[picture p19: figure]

Hình 3.15. Module 1 Relay 12V Kích Mức Cao/Thấp

Thông số kỹ thuật:

- Nguồn cấp: 12VDC.
- Relay tiêu thụ dòng khoảng 80mA.
- Điện thế đóng ngắt tối đa: AC250V ~ 10A hoặc DC30V ~ 10A.
- Có đèn báo đóng ngắt trên mỗi Relay.
- Có thể chọn mức tín hiệu kích 0 hoặc 1 qua jumper.
- Kích thước: 5.0x2.6x1.9 cm

❖ Nam châm điện

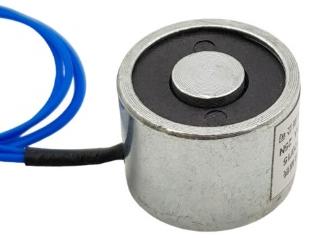
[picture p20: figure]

Hình 3.16. Nam châm điện

Thông số kỹ thuật:

- Điện áp cấp: 12VDC
- Dòng tiêu thụ: 0.25A
- Công suất: 3W
- Lực hút: 25N (~2.5kg)
- Đường kính: 20mm

- Lõi sắt: 8mm
- Độ dày: 15mm
- Nhiệt độ hoạt động tối đa 130°C
- Trọng lượng: 25g

❖ Công tắc hành trình

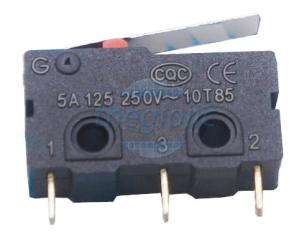
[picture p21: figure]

Hình 3.17. Công tắc hành trình

Thông số kĩ thuật:

- Loại: cần lẫy
- Cách gắn: hàn
- Dòng định mức: 5A
- Điện áp AC max: 250 VAC
- Vật liệu tiếp điểm: hợp kim bạc
- Tuổi thọ: 3.000.000 lần
- Nhiệt độ hoạt động: -25 → +85°C

❖ Khớp nối trục động cơ mặt bích

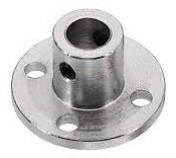
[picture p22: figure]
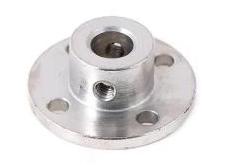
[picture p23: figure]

Hình 3.18. Khớp nối trục động cơ mặt bích 6mm và 8mm

❖ Puly GT2, bước răng 2mm

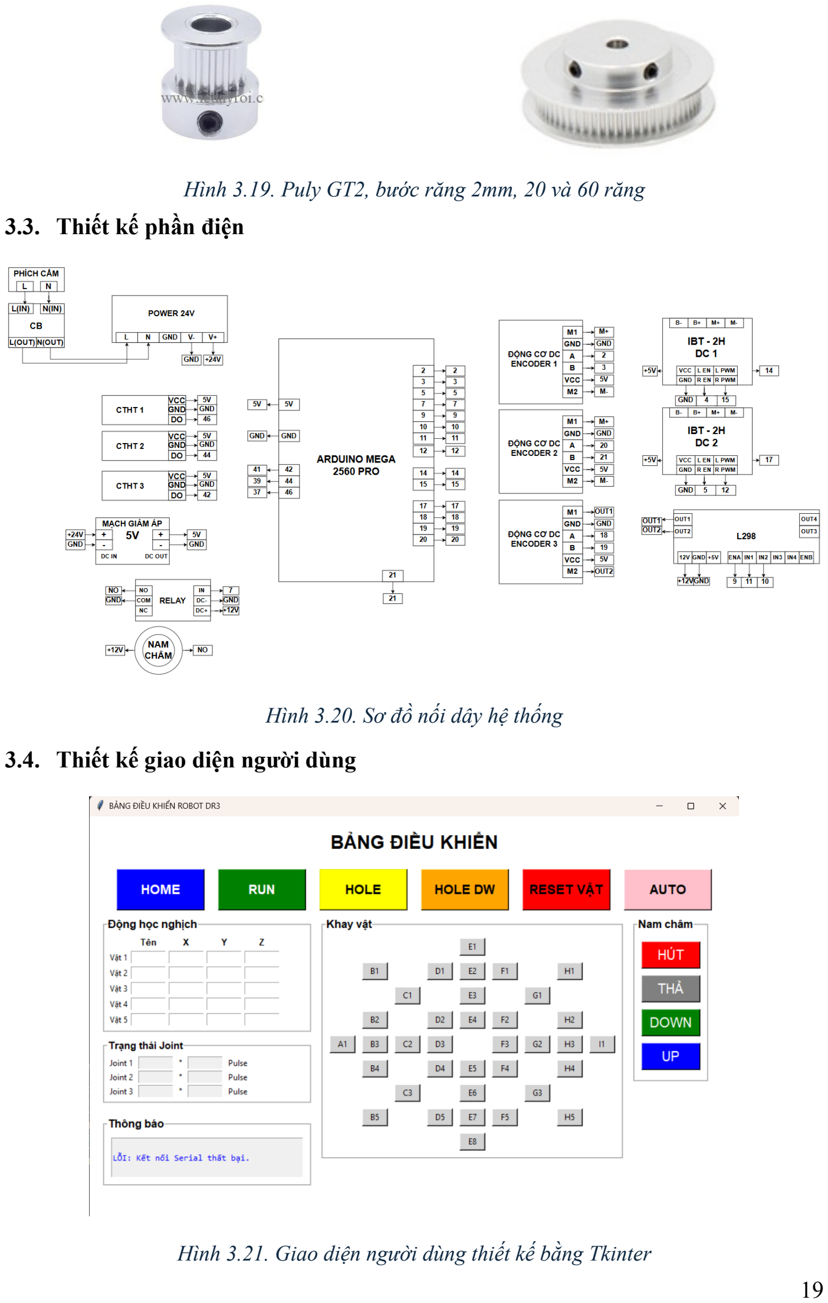
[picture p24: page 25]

Hình 3.19. Puly GT2, bước răng 2mm, 20 và 60 răng

### 3.3. Thiết kế phần điện

Hình 3.20. Sơ đồ nối dây hệ thống

### 3.4. Thiết kế giao diện người dùng

Hình 3.21. Giao diện người dùng thiết kế bằng Tkinter

CHƯƠNG 4. THIẾT KẾ THUẬT TOÁN CHO HỆ THỐNG

### 4.1. Tổng quan về thuật toán của hệ thống

Hệ thống sử dụng cấu trúc điều khiển phản hồi vòng kín với đa vòng lặp (Cascade

Control) kết hợp cùng kỹ thuật bù trước (Feedforward) và quy hoạch quỹ đạo thời gian

thực.

Sơ đồ dòng chảy tín hiệu:

- Input: Người dùng gửi lệnh tọa độ góc qua Serial (lệnh SET a b c).
- Trajectory Planner: Hệ thống tính toán các hệ số đa thức bậc 5 để tạo ra đường

đi mịn (S-Curve).
- Outer Loop (Vị trí): Chạy ở tần số 50Hz, tính toán sai số vị trí để đưa ra vận tốc

yêu cầu.

- Inner Loop (Vận tốc): Chạy ở tần số 200Hz, tiếp nhận vận tốc yêu cầu, kết hợp

cùng các thành phần bù (Trọng lực, Quán tính) để xuất tín hiệu PWM điều khiển động

cơ.

### 4.2. Quy hoạch quỹ đạo Quintic S-Curve (Trajectory Planning)

Thay vì thay đổi vị trí đột ngột gây sốc cơ khí, hệ thống sử dụng đa thức bậc 5 để

quy hoạch vị trí p(t) sao cho vận tốc và gia tốc tại điểm đầu và điểm cuối đều bằng 0.

Phương trình toán học:

2 | 3 | 4 | 5
0 | 1 | 2 | 3 | 4 | 5 p t | a | a t a t | a t | a t | a t () = | + | + | + | + | +
(4.1)

Trong mã nguồn, các hệ số này được tính toán trong hàm plan_quintic_trajectory:

- a0, a1, a2: Xác định trạng thái ban đầu (vị trí, vận tốc, gia tốc đầu).
- a3, a4, a5: Xác định dựa trên khoảng cách cần di chuyển và tổng thời

gian T.

Tác dụng: Kỹ thuật này triệt tiêu hoàn toàn hiện tượng rung lắc (Jerk) do sự thay

đổi gia tốc đột ngột, giúp cánh tay robot di chuyển cực kỳ êm ái.

### 4.3. Thiết kế bộ điều khiển phối hợp (Controller Design)

### 4.3.1. Bộ điều khiển vị trí (Outer Loop)

Hàm positionPID thực hiện nhiệm vụ duy trì bám đuổi vị trí theo quỹ đạo đã lập. Công

thức tính vận tốc mục tiêu (vtarget) dựa trên sai số vị trí epos:

arg | _ | _ | _ . | . | .

pos
t | et | p pos | pos | i pos | pos | d pos

de
v | K | e | K | e dt K
dt
= | + | + ò
(4.2)

Hệ thống sử dụng cơ chế Anti-windup bằng cách giới hạn tích phân (constrain(i_pos, -

20000, 20000)) và giảm dần tích phân khi sai số nằm trong vùng chết (deadzone) để

tránh vọt lố.

### 4.3.2. Bộ điều khiển vận tốc tích hợp bù động lực học (Inner Loop)

Hàm velocityPID là trái tim của thuật toán, nơi tổng hợp nhiều thành phần lực để

tạo ra đầu ra PWM tối ưu:

PWM | u | FF | FF | Grav total | PID vel | v | a = | + | + | + _
(4.3)
- Bù trọng lực (Gravity Compensation): Tính toán dựa trên mô hình tĩnh học Kgrav. sin (θ). Thành phần này giúp triệt tiêu trọng lượng của cánh tay, cho

phép bộ PID chỉ tập trung vào việc di chuyển mà không phải "gồng" mình giữ

tay máy khỏi rơi.
- Bù trước vận tốc & gia tốc (Feedforward):
- FFv = Kffv

. vtarget: Bù ma sát động.

- FFa = Kffa. atarget: Bù lực quán tính khi bắt đầu tăng tốc hoặc giảm tốc.

Lọc nhiễu (Low Pass Filter): Vận tốc đọc từ Encoder thường có nhiễu cao, hệ thống

sử dụng bộ lọc số alpha để làm mượt dữ liệu trước khi đưa vào PID vòng trong.

CHƯƠNG 5. ĐÁNH GIÁ TRÊN THỰC NGHIỆM

### 5.1. Giới thiệu môi trường thực nghiệm

Yêu cầu của bài toán là thiết kế và lập trình cánh tay robot có khả năng vận hành

theo chu trình tự động trên khay chứa nhiều lỗ nhỏ. Trên khay, các viên bi được đặt ngẫu

nhiên hoặc theo vị trí cố định trong các lỗ nhỏ, và nhiệm vụ của robot là lần lượt tiếp

cận từng lỗ, gắp viên bi ra khỏi lỗ rồi đưa về vị trí đích là lỗ tròn nằm ở trung tâm khay.

Để đáp ứng đúng yêu cầu, robot phải xác định được tọa độ chính xác của từng lỗ nhỏ

(theo hệ tọa độ của khay), sau đó di chuyển đầu gắp đến đúng tâm lỗ với độ sai lệch nhỏ

nhằm tránh va chạm với thành lỗ. Khi tiếp cận, robot hạ trục Z xuống độ cao phù hợp

để gắp được viên bi bằng cơ cấu hút bằng nam châm.

Sau khi gắp thành công, robot nâng viên bi lên độ cao an toàn, di chuyển theo quỹ

đạo đã lập kế hoạch để tránh chạm vào các vị trí lỗ khác hoặc thành khay, rồi tiến hành

đưa viên bi về lỗ tròn ở giữa. Tại vị trí trung tâm, robot phải thả viên bi đúng vào lỗ tròn,

đảm bảo viên bi rơi đúng tâm, không bị rơi lệch ra ngoài. Quá trình này được lặp lại liên tục theo danh sách các lỗ nhỏ cần gắp cho đến khi hoàn thành việc thu gom toàn bộ viên

bi. Ngoài ra, hệ thống cần đáp ứng các tiêu chí như: chuyển động ổn định, độ lặp lại cao,

thời gian chu trình hợp lý và có thể giám sát/điều khiển thông qua giao diện để quan sát

trạng thái hoạt động của robot trong quá trình vận hành.

### 5.2. Các bước xây dựng hệ thống trên môi trường thực nghiệm

Phương pháp thực hiện để xác định tọa độ chính xác của từng lỗ nhỏ trên khay

được tiến hành theo các bước sau: trước hết nhóm thiết lập một hệ trục tọa độ gắn với

khay bằng cách chọn gốc tọa độ H tại tâm lỗ tròn trung tâm, sau đó chọn thêm hai lỗ

chuẩn cố định trên khay để xác định hướng của hai trục X và Y. Tiếp theo, robot được

đưa lần lượt đến đúng tâm của các điểm chuẩn này bằng cách đo thực tế, từ đó thu được

tọa độ của H và các điểm trong hệ tọa độ robot. Dựa trên các điểm đã xác định, nhóm

xây dựng các vectơ đơn vị theo phương trục X và Y của khay, qua đó xác định đúng hướng đặt khay ngay cả khi khay bị xoay hoặc lệch nhẹ so với vị trí ban đầu. Sau đó,

nhóm lập bảng độ lệch (Δx, Δy) của từng lỗ nhỏ so với gốc H (dựa vào đo thực tế) và

áp dụng phép cộng vectơ để chuyển đổi sang hệ tọa độ robot: tọa độ mỗi lỗ được tính

bằng tọa độ gốc H cộng với Δx theo trục X và Δy theo trục Y. Cuối cùng, nhóm tiến hành kiểm tra lại một số lỗ tiêu biểu bằng cách cho robot chạy thử đến các tọa độ đã

tính, quan sát sai lệch và hiệu chỉnh khi cần thiết, nhằm đảm bảo robot luôn tiếp cận

đúng tâm lỗ để gắp bi ổn định và thả chính xác về lỗ trung tâm.

### 5.3. Thảo luận về các kết quả

Kết quả thực hiện cho thấy hệ thống robot đã vận hành đúng theo yêu cầu đề ra.

Trong quá trình thử nghiệm, cánh tay robot di chuyển lần lượt đến các vị trí lỗ nhỏ theo

tọa độ đã thiết lập, tiếp cận đúng tâm lỗ và thực hiện thao tác gắp viên bi một cách ổn

định. Cơ cấu gắp hoạt động hiệu quả, đảm bảo viên bi được lấy ra khỏi lỗ mà không xảy

ra hiện tượng rơi hoặc kẹt trong quá trình nâng lên và di chuyển. Sau khi gắp, robot vận

chuyển viên bi về vị trí lỗ tròn trung tâm theo quỹ đạo đã lập trình và thả viên bi chính

xác vào đúng vị trí đích. Kết quả tổng thể ghi nhận robot gắp thành công 5/5 viên bi và

đưa toàn bộ về đúng lỗ trung tâm, chứng minh tính đúng đắn của thuật toán điều khiển,

độ chính xác định vị và khả năng lặp lại của mô hình khi vận hành thực tế.

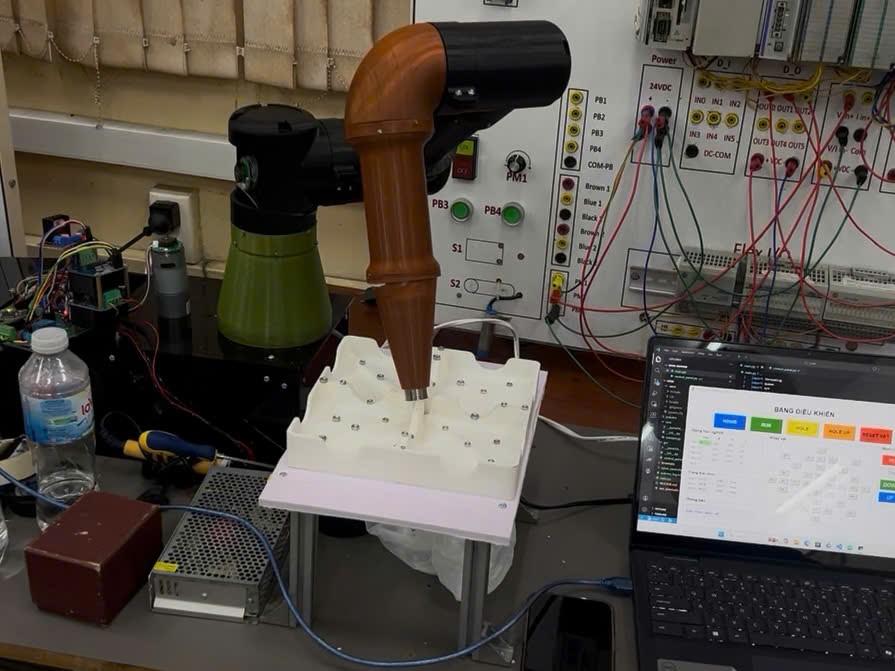
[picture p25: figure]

Hình 5.1. Kết quả phần cứng

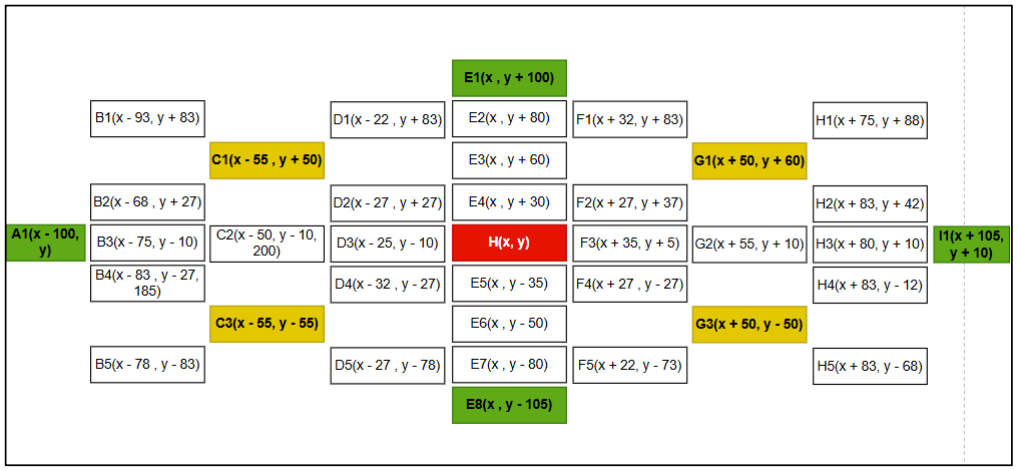
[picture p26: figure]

Hình 5.2. Hệ tọa độ khay gắp

CHƯƠNG 6. KẾT LUẬN

### 6.1. Kết luận

Thông qua quá trình nghiên cứu và thực hiện dự án, nhóm đã chế tạo thành công

mô hình robot DR3 3 bậc tự do với cấu trúc được tối ưu hóa hoàn toàn bằng công nghệ

in 3D, giúp hệ thống có khối lượng nhẹ và tính thẩm mỹ cao. Hệ thống sử dụng động cơ

DC kết hợp với Encoder phản hồi vòng kín, cho phép kiểm soát vị trí chính xác thông

qua thuật toán động học nghịch được tích hợp trên giao diện Python Tkinter. Kết quả

vận hành thực tế cho thấy cánh tay robot đã thực hiện tốt nhiệm vụ gắp các viên bi từ vị

trí xác định và thả về lỗ đích (HOLE) một cách đồng bộ thông qua giao tiếp Serial với

Arduino, đáp ứng đầy đủ các yêu cầu về độ chính xác và tính trực quan trong vận hành.

### 6.2. Hướng phát triển tiếp theo

Để nâng cao hiệu suất và tính ứng dụng, hệ thống có thể được tích hợp thêm công

nghệ xử lý ảnh giúp robot tự động nhận diện vị trí viên bi thay vì thao tác chọn vị trí thủ công trên giao diện, đồng thời bổ sung thêm bậc tự do thứ 4 tại cổ tay để tăng cường

tính linh hoạt. Việc ứng dụng các thuật toán quy hoạch quỹ đạo thông minh kết hợp với

nghiên cứu nâng cấp khung xương sang vật liệu nhôm trong tương lai sẽ giúp robot di

chuyển mượt mà hơn, giảm thiểu rung lắc cho cấu trúc nhựa in 3D và tăng cường tải

trọng gắp.

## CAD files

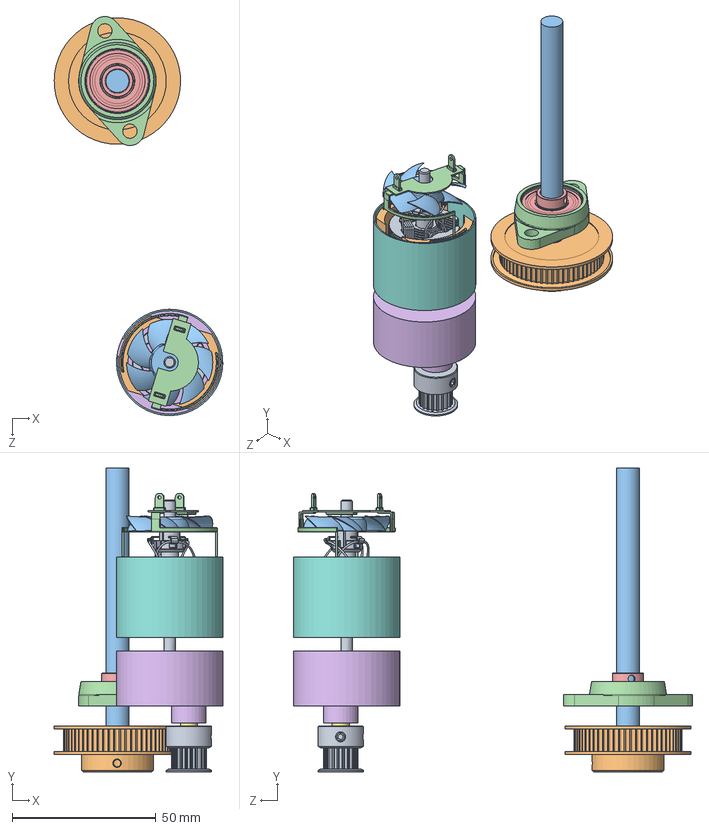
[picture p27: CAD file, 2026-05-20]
stl/robot_done/robot_done.SLDASM
58.7 x 105.7 x 138.9 mm
PulyGT2 16 răng trục 5mm
PulyGT2 60 răng trục 8mm - NShop
de_8 - Copy
FLANGE^Vòng bi KFL08
BEARING^Vòng bi KFL08
Reduction box body
Shaft
Cover
Rotor
Magnets
Fan
Terminals
Gear 1
Gear 2
Gear 3

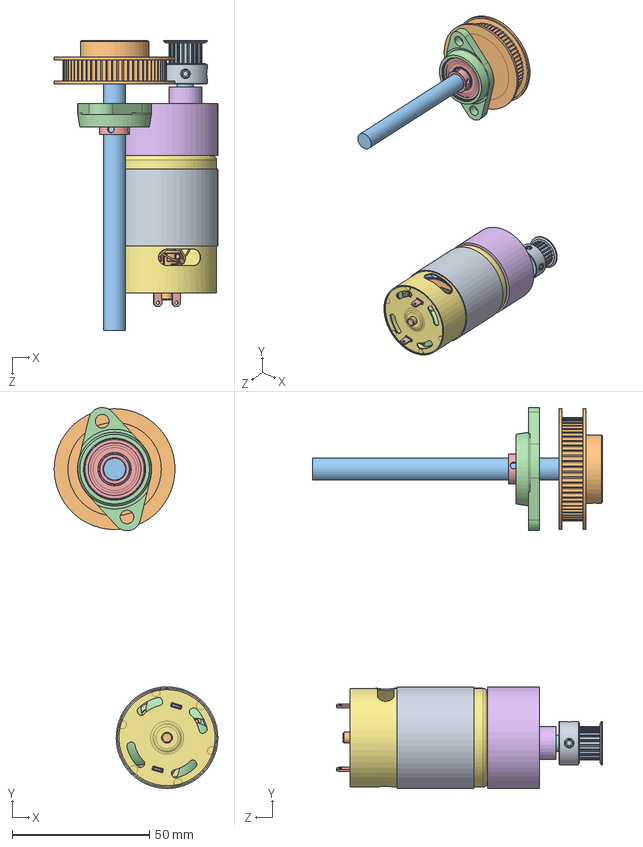
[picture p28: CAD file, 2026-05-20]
stl/tonghop/BASE/BASE hoan thien.SLDASM
59.6 x 138.7 x 105.7 mm
PulyGT2 16 răng trục 5mm
PulyGT2 60 răng trục 8mm - NShop
de_8 - Copy
FLANGE^Vòng bi KFL08
BEARING^Vòng bi KFL08
Reduction box body
Motor body
Shaft
Cover
Rotor
Magnets
Fan
Terminals
Gear 1
Gear 2
Gear 3

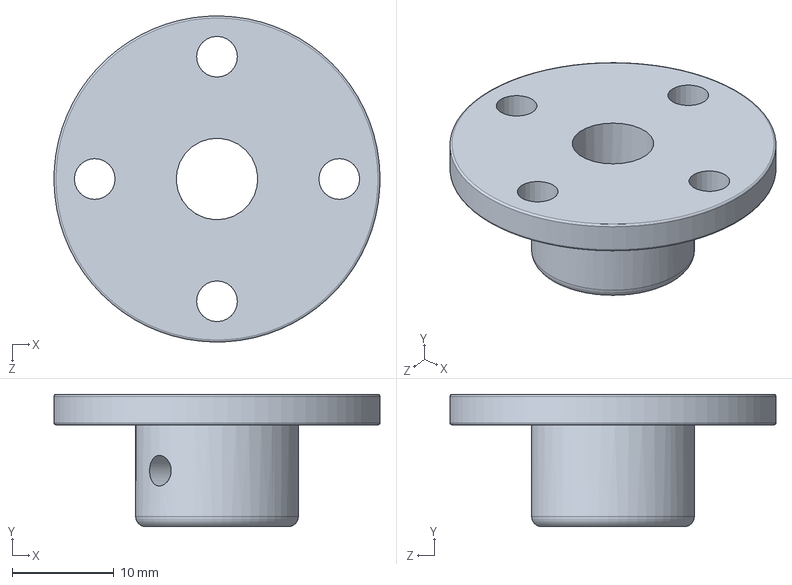
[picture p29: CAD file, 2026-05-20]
stl/tonghop/Link1/Link1 Assembly.SLDASM
32.0 x 13.0 x 32.0 mm

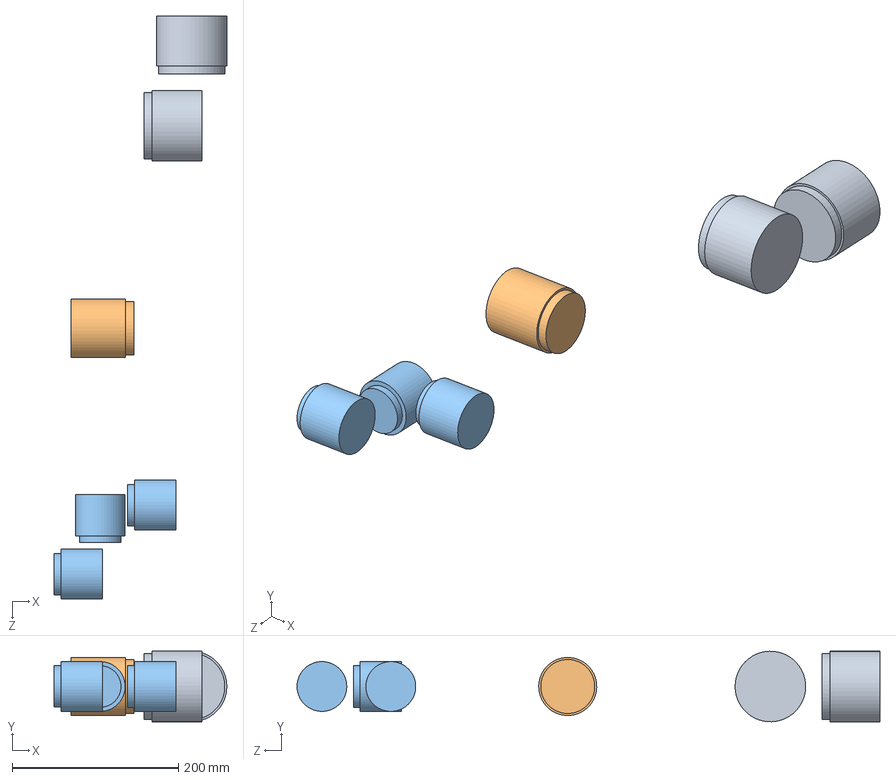
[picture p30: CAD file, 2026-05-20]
stl/UR3 Assembly.SLDASM
208.0 x 84.9 x 702.0 mm
motor1 x 2
Motor2
Motor3 x 3

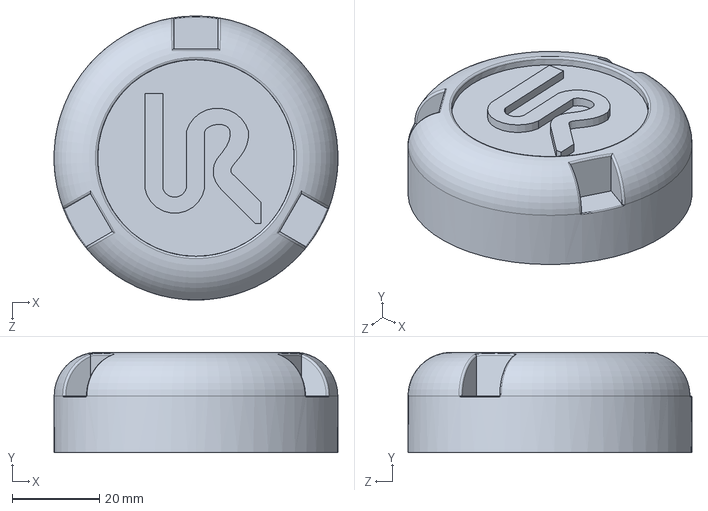
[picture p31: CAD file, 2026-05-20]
stl/Size 0 C.SLDPRT
65.0 x 23.0 x 65.0 mm

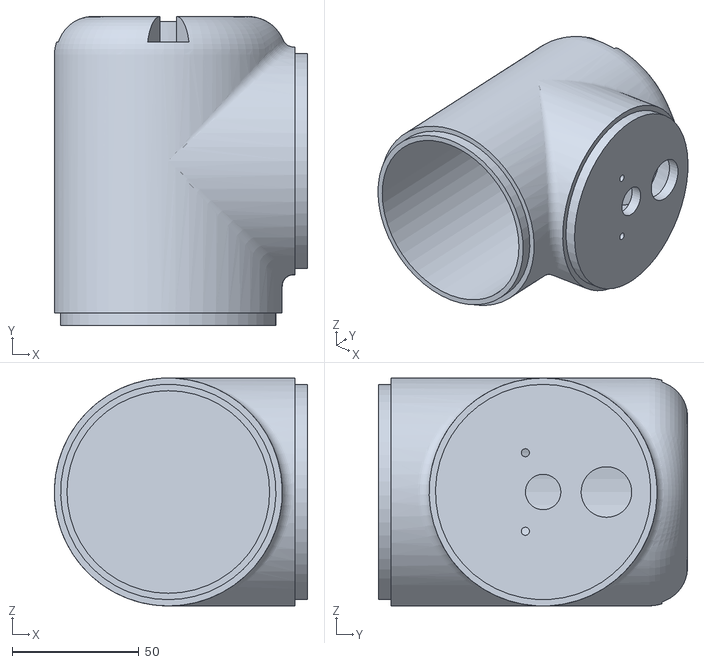
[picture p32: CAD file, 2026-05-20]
stl/tonghop/In/Link1/shoulder - base 1.STL
100.0 x 122.0 x 90.0

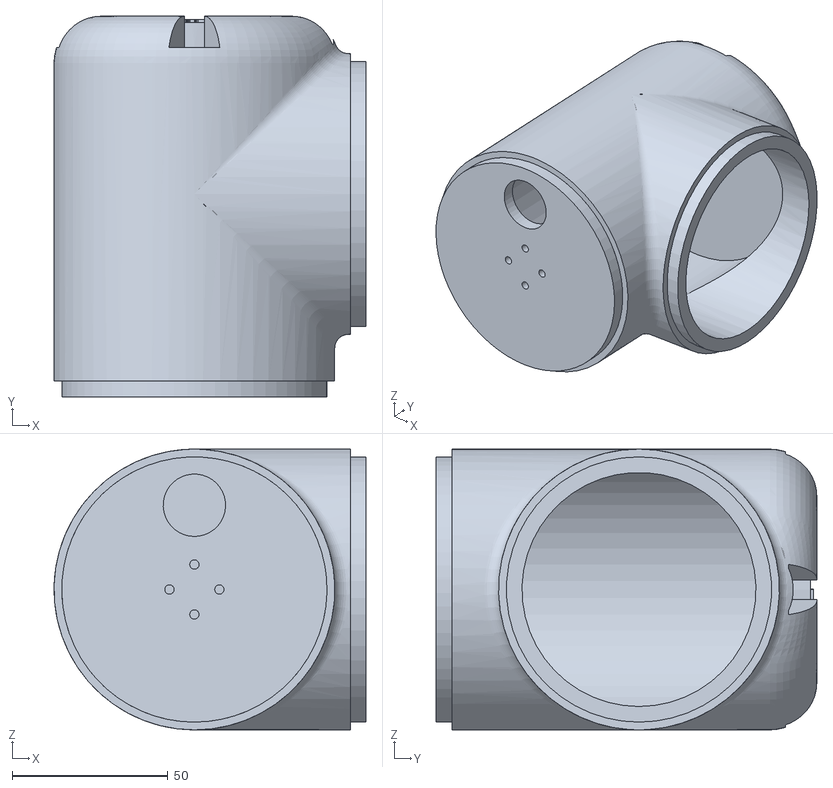
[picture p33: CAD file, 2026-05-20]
stl/tonghop/In/Link2/shoulder - base 1.STL
100.0 x 122.0 x 90.0

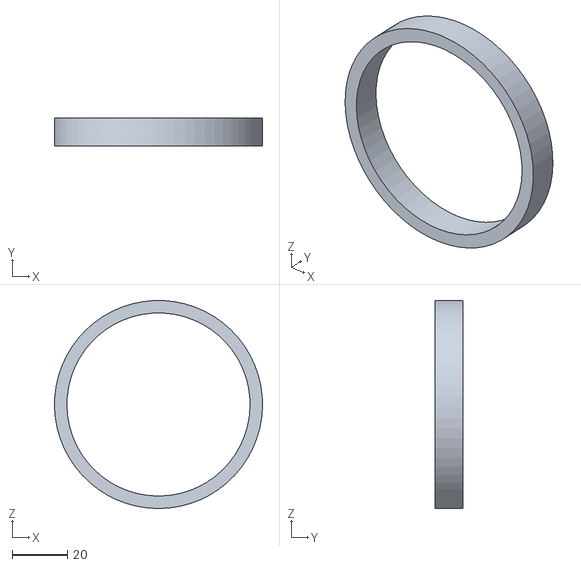
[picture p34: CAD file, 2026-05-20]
stl/tonghop/In/Link3/size 1 flange.STL
75.0 x 10.0 x 75.0

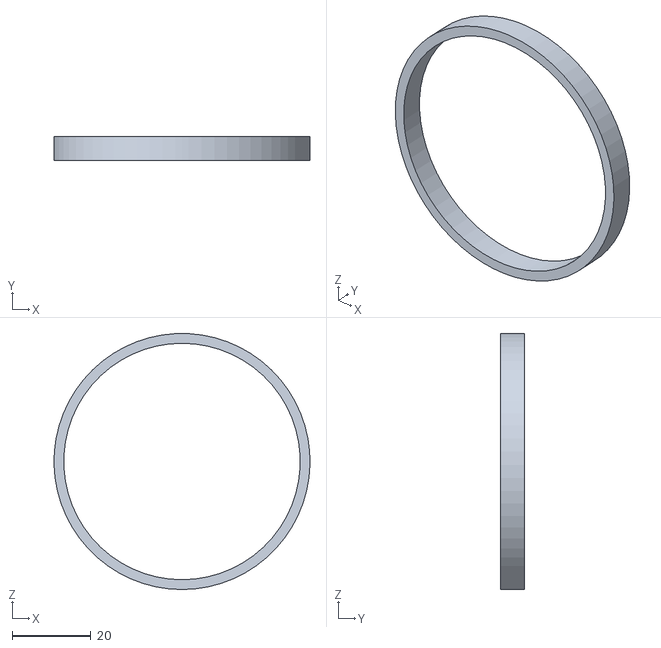
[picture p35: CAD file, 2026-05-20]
stl/tonghop/In/Link3/đã fix/size 0 flange.STL
65.0 x 6.00 x 65.0

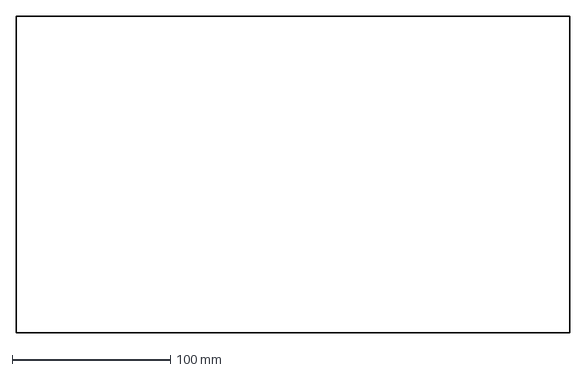
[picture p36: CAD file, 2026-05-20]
stl/tonghop/In/MikaBase/FileSTEP/MẶT2.DXF
350.0 x 200.0 mm

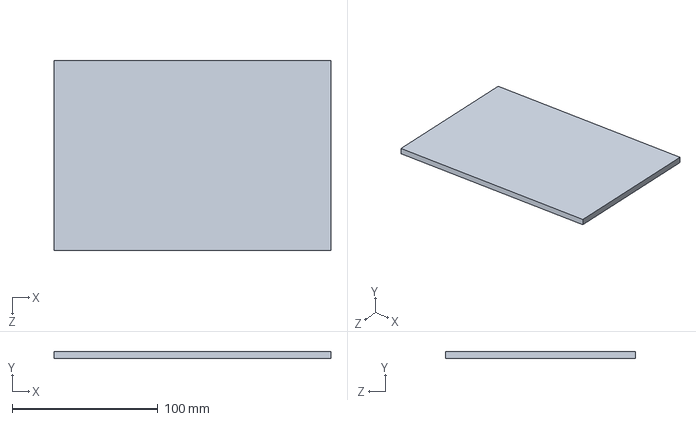
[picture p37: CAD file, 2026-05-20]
stl/tonghop/In/MikaBase/MẶT3.SLDPRT
190.0 x 5.00 x 130.0 mm

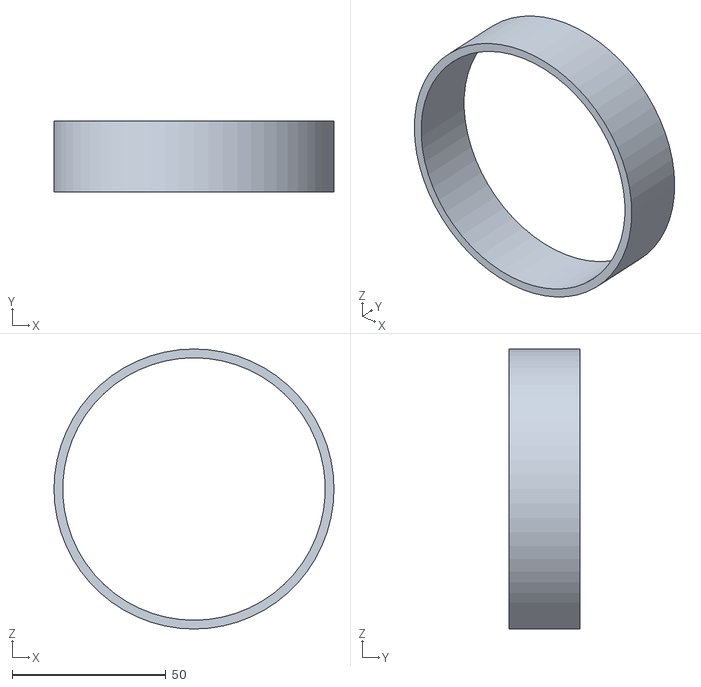
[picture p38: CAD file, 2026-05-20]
stl/tonghop/In/vongkhoplink1.STL
91.0 x 23.0 x 91.0

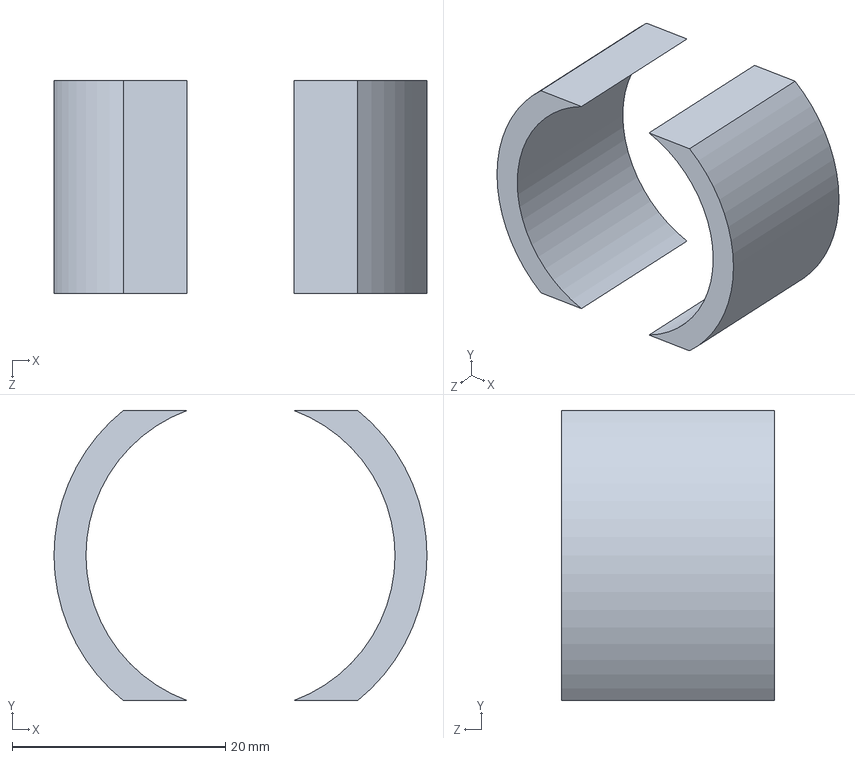
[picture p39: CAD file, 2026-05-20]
stl/tonghop/Motor JGB37-545/Magnets.SLDPRT
35.0 x 27.2 x 20.0 mm

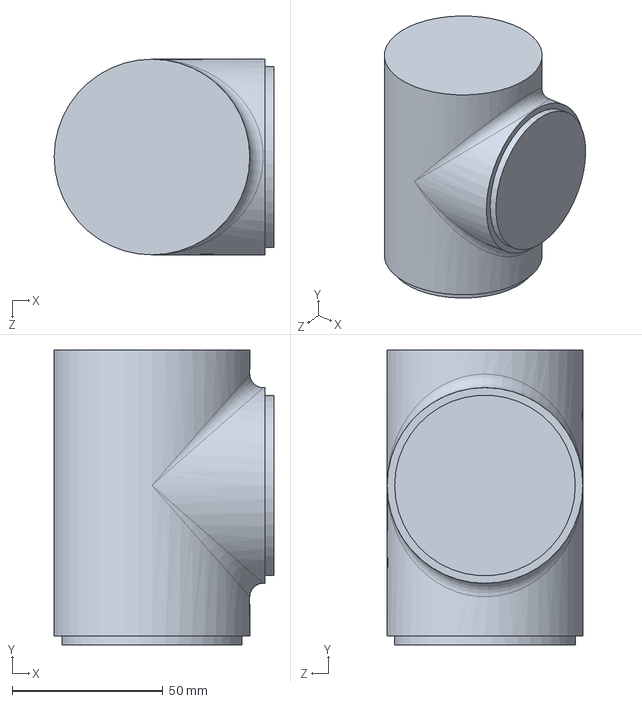
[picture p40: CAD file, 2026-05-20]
stl/size 0 S3.SLDPRT
73.0 x 98.0 x 65.0 mm

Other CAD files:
stl/tonghop/Link2/Link2 Assembly.SLDASM
stl/tonghop/Link3/Link3 Assembly.SLDASM
stl/tonghop/BASE/StepMotor 42HSG48-1504A.SLDPRT
stl/tonghop/In/Link1/size 2 flange.STL
stl/25mm DC Motor.stl
stl/Arm 2.SLDPRT
stl/Base Joint.SLDPRT
stl/NamCham.SLDPRT
stl/Namchammoi.SLDPRT
stl/Size 1 C.SLDPRT
stl/Size 2 C.SLDPRT
stl/Tool holder.SLDPRT
stl/Upper arm.SLDPRT
stl/elbow.SLDPRT
stl/shoulder - base 1.SLDPRT
stl/size 0 F.SLDPRT
stl/size 0 S1.SLDPRT
stl/size 1 F.SLDPRT
stl/size 1 S.SLDPRT
stl/size 2 F.SLDPRT
stl/tonghop/BASE/Base.SLDPRT
stl/tonghop/In/Link1/Base Joint.STL
stl/tonghop/In/Link2/Upper arm.STL
stl/tonghop/In/Link2/shoulder - base 1_da chinh.SLDPRT
stl/tonghop/In/Link2/size 1 flange.STL
stl/tonghop/In/Link2/size 1 shoulder.STL
stl/tonghop/In/Link2/size 1 shoulder_đã chỉnh.SLDPRT
stl/tonghop/In/Link2/size 2 flange.STL
stl/tonghop/In/Link3/Arm 2.STL
stl/tonghop/In/Link3/Namchammoi.STL
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

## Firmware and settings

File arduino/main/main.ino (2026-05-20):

/******************************************
 * PID CASCADE + QUINTIC S-CURVE 
 * (ĐÃ SỬA: DÙNG THƯ VIỆN ENCODER.H VÀ XUNG X4 - KHÔNG DÙNG KALMAN FILTER)
 * Full sketch with motor_enabled state
 * - Outer position PID: 50 Hz (20 ms)
 * - Inner velocity PID: 200 Hz (5 ms)
 * - Commands: SET a b c | HOME | HUT | THA 
 * - Đã loại bỏ hoàn toàn cơ chế bù trừ xung khi đảo chiều (anti-backlash).
 * * ĐÃ KHẮC PHỤC LỖI STRAY CHARACTER ('\302', '\240')
 ******************************************/

// BẮT BUỘC: Thêm thư viện Encoder.h
#include <Encoder.h>
#include <math.h> // Để dùng các hàm toán học như sin, copysign, fabs

// Các hằng số cho phép tính toán (cần thiết cho joint_angle_rad)
#ifndef DEG_TO_RAD
#define DEG_TO_RAD 0.01745329251994329576923690768489 // M_PI / 180
#endif

// Arduino Mega hoặc Mega 2560 PINOUT
const int M1_IN1 = 14;
const int M1_IN2 = 15;
const int M1_ENA = 4;
const int ENC1_A = 3; 	 // INT0
const int ENC1_B = 2; 	 // INT1

const int M2_IN1 = 17;
const int M2_IN2 = 12;
const int M2_ENA = 5;
const int ENC2_A = 21; // INT5
const int ENC2_B = 20; // INT4

const int M3_IN1 = 11;
const int M3_IN2 = 10;
const int M3_ENA = 9;
const int ENC3_A = 18; // INT3
const int ENC3_B = 19; // INT2

const int ENA = 7; 	 	 // control for solenoid / vacuum
const int CTHT_1 = 46;
const int CTHT_2 = 44;
const int CTHT_3 = 42;

/********* Khai báo Encoder (SỬ DỤNG THƯ VIỆN) **********/
// Tham số: (Chân B, Chân A) để tương thích với thư viện Encoder.h khi chân A là chân ngắt
Encoder enc1_lib(ENC1_B, ENC1_A); 
Encoder enc2_lib(ENC2_B, ENC2_A);
Encoder enc3_lib(ENC3_B, ENC3_A);


/********* Encoder Count **********/
long enc1 = 0; 
long enc2 = 0;
long enc3 = 0;

/********* Velocity Calculation **********/
long prev_enc1 = 0;
long prev_enc2 = 0;
long prev_enc3 = 0;
float current_velocity1 = 0; // xung / ms (Tính toán trực tiếp)
float current_velocity2 = 0;
float current_velocity3 = 0;

/********* CASCADE PID (Hệ số đã được điều chỉnh) **********/
const int STABLE_COUNT = 500; // Số lần ổn định liên tiếp để kết thúc lệnh

// Position PID gains (outer)
float Kp_pos[] = {0, 8.5, 7.5, 7.5}; 
float Ki_pos[] = {0, 0.0, 0.0, 	0.0};
float Kd_pos[] = {0, 0.8, 0.1, 	0.15}; 

// Velocity PID gains (inner)
float Kp_vel[] = {0, 6.3, 6.8, 8.5}; 
float Ki_vel[] = {0, 0.2, 0.1 ,1.8}; 
float Kd_vel[] = {0, 0.0, 0.0, 0.0}; 

float Kff_v[] = {0, 0,3.1, 6.1}; 
float Kff_a[] = {0, 0.0,0.01, 0.03}; 
float Kgrav[] = {0, 0, 2.1, 1.5};

int last_dir[4] = {0,0,0,0}; // Vẫn giữ lại biến này nhưng không dùng trong PID
float vel_lpf[4] = {0, 0, 0, 0};
// integrators and previous errors
float i_pos[4] = {0,0,0,0}, p_pos[4] = {0,0,0,0};
float i_vel[4] = {0,0,0,0}, p_vel[4] = {0,0,0,0};

// LPF for PWM output smoothing
float prev_out[4] = {0,0,0,0};
const float alpha = 0.6; // Hệ số LPF cho PWM 

// PWM limits
float pwm_limit = 180.0; 
const float PWM_DEADZONE = 4; // Không dùng

/********* Timing **********/
const unsigned long VEL_INTERVAL_MS = 5; 	// 200 Hz
const unsigned long POS_INTERVAL_MS = 20; 	// 50 Hz
unsigned long lastVel = 0;
unsigned long lastPos = 0;

/********* Encoder -> degree (mech config) - XUNG X4 **********/
const float Hesotruyen = 1;
// M1: (16 * 270 * (60/20) / 1) * 4
const float pulsesPerRevolution1 = (16.0 * 270.0 * (60.0 / (20.0 * Hesotruyen))) * 4.0; 
const float pulsesPerDegree1 = pulsesPerRevolution1 / 360.0;
// M2: 16 * 270 * 4
const float pulsesPerRevolution2 = 16.0 * 506.0 * 4.0; 
const float pulsesPerDegree2 = pulsesPerRevolution2 / 360.0;
// M3: 11 * 90 * 4
const float pulsesPerRevolution3 = 11.0 * 90.0 * 4.0; 
const float pulsesPerDegree3 = pulsesPerRevolution3 / 360.0;

/********* Trajectory (quintic S-curve) **********/
const float MAX_VELOCITY = 5.0; 	// xung / ms
const float MIN_TRAJ_TIME =1.5; 	 // s (min)
float acoef[4][6]; // Hệ số quỹ đạo bậc 5
float traj_T[4] = {0,0,0,0};
unsigned long traj_t0_ms[4] = {0,0,0,0};
bool traj_active[4] = {false,false,false,false};

float start_position[4] = {0,0,0,0};
float target_position[4] = {0,0,0,0};

float s_curve_target_pos[4] = {0,0,0,0};
float s_curve_target_vel[4] = {0,0,0,0}; // xung / ms
float s_curve_target_acc[4] = {0,0,0,0}; // xung / ms^2

float traj_vel[4]; 	// vận tốc từ S-curve (không dùng trực tiếp, chỉ để debug)
float pid_vel_cmd[4]; // vận tốc PID hiệu chỉnh

/********* Control / state **********/
long final_target_pulse[4] = {0,0,0,0};
long pulse[4] = {0,0,0,0};
String inputString = "";
bool stringComplete = false;
bool start_homing[4] = {0,0,0,0};
long nStable[4] = {0,0,0,0};
bool jobDoneArr[4] = {true,true,true,true}; 
const int allowError1 = 3;
const int allowError2 = 3;
const int allowError3 = 3;
bool has_moved = false;

// NEW: motor enabled state
bool motor_enabled = false;
bool is_all_done = false;

/********* Prototypes **********/
float joint_angle_rad(int m);
void update_encoder_readings();
void calculate_current_velocity(); 
void plan_quintic_trajectory(int m);
void sample_trajectory(int m);
void positionPID(int m);
void velocityPID(int m);
void applyPWM(int m, float pwm);
void resetPIDState();
void brakeAll();
void stopAll();
void startHomingSequence();
void printlog();


/******************************************
 Motor helper functions 
******************************************/
void fwd1(int pwm) { digitalWrite(M1_IN1, LOW); 	digitalWrite(M1_IN2, HIGH); analogWrite(M1_ENA, pwm); }
void rev1(int pwm) { digitalWrite(M1_IN1, HIGH); digitalWrite(M1_IN2, LOW); 	analogWrite(M1_ENA, pwm); }
void stop1() 	 	 { digitalWrite(M1_IN1, LOW); 	digitalWrite(M1_IN2, LOW); 	analogWrite(M1_ENA, 0); }
void brake1() 	 { digitalWrite(M1_IN1, HIGH); digitalWrite(M1_IN2, HIGH); analogWrite(M1_ENA, 255); }

void fwd2(int pwm) { digitalWrite(M2_IN1, LOW); digitalWrite(M2_IN2, HIGH); 	analogWrite(M2_ENA, pwm); }
void rev2(int pwm) { digitalWrite(M2_IN1, HIGH); 	digitalWrite(M2_IN2, LOW); analogWrite(M2_ENA, pwm); }
void stop2() 	 	 { digitalWrite(M2_IN1, LOW); 	digitalWrite(M2_IN2, LOW); 	analogWrite(M2_ENA, 0); }
void brake2() 	 { digitalWrite(M2_IN1, HIGH); digitalWrite(M2_IN2, HIGH); analogWrite(M2_ENA, 255); }

void fwd3(int pwm) { digitalWrite(M3_IN1, LOW); 	digitalWrite(M3_IN2, HIGH); analogWrite(M3_ENA, pwm); }
void rev3(int pwm) { digitalWrite(M3_IN1, HIGH); digitalWrite(M3_IN2, LOW); 	analogWrite(M3_ENA, pwm); }
void stop3() 	 	 { digitalWrite(M3_IN1, LOW); 	digitalWrite(M3_IN2, LOW); 	analogWrite(M3_ENA, 0); }
void brake3() 	 { digitalWrite(M3_IN1, HIGH); digitalWrite(M3_IN2, HIGH); analogWrite(M3_ENA, 255); }


/******************************************
 Cập nhật giá trị Encoder (ĐỌC TỪ THƯ VIỆN)
 ******************************************/
void update_encoder_readings() {
	noInterrupts();
	enc1 = enc1_lib.read();
	enc2 = enc2_lib.read();
	enc3 = enc3_lib.read();
	interrupts();
}

/******************************************
 calculate velocities (xung / ms) - TÍNH TRỰC TIẾP
 ******************************************/
void calculate_current_velocity() {
	// Tính vận tốc dựa trên sự thay đổi encoder trong khoảng thời gian VEL_INTERVAL_MS
	current_velocity1 = (float)(enc1 - prev_enc1) / (float)VEL_INTERVAL_MS;
	current_velocity2 = (float)(enc2 - prev_enc2) / (float)VEL_INTERVAL_MS;
	current_velocity3 = (float)(enc3 - prev_enc3) / (float)VEL_INTERVAL_MS;

	prev_enc1 = enc1;
	prev_enc2 = enc2;
	prev_enc3 = enc3;
}

/******************************************
 Quintic trajectory planner 
 ******************************************/
void plan_quintic_trajectory(int m) {
	float p0 = start_position[m];
	float pf = target_position[m];
	float delta = pf - p0;
	float dist = fabs(delta);

	float T = MIN_TRAJ_TIME;
	if (dist > 0.0) {
		float max_vel_s = MAX_VELOCITY * 1000.0; // Chuyển sang xung / giây
		float T_calc = 2.0 * dist / max_vel_s; // s
		T = T_calc;
	}
	if (T < MIN_TRAJ_TIME) T = MIN_TRAJ_TIME;

	float T2 = T*T, T3 = T2*T, T4 = T3*T, T5 = T4*T;
	// Các hệ số của quỹ đạo bậc 5: p(t) = a0 + a1*t + a2*t^2 + a3*t^3 + a4*t^4 + a5*t^5
	acoef[m][0] = p0;
	acoef[m][1] = 0.0; 
	acoef[m][2] = 0.0; 
	acoef[m][3] = (10.0*(pf - p0)) / T3;
	acoef[m][4] = (-15.0*(pf - p0)) / T4;
	acoef[m][5] = (6.0*(pf - p0)) / T5;

	traj_T[m] = T;
	traj_t0_ms[m] = millis();
	traj_active[m] = true;
}

/******************************************
 sample trajectory
 ******************************************/
void sample_trajectory(int m) {
	if (!traj_active[m]) {
		s_curve_target_pos[m] = target_position[m];
		s_curve_target_vel[m] = 0.0;
		s_curve_target_acc[m] = 0.0;
		return;
	}
	unsigned long tnow_ms = millis();
	float t_rel = (tnow_ms - traj_t0_ms[m]) / 1000.0; // Chuyển sang giây
	float T = traj_T[m];

	if (t_rel >= T) {
		s_curve_target_pos[m] = target_position[m];
		s_curve_target_vel[m] = 0.0;
		s_curve_target_acc[m] = 0.0;
		traj_active[m] = false;
		return;
	}
	float t = t_rel;
	float t2 = t*t, t3 = t2*t, t4 = t3*t;
	
	// Tính vị trí
	float pos = acoef[m][0] + acoef[m][1]*t + acoef[m][2]*t2 + acoef[m][3]*t3 + acoef[m][4]*t4 + acoef[m][5]*t2*t3;
	// Tính vận tốc (xung / giây)
	float vel_s = acoef[m][1] + 2.0*acoef[m][2]*t + 3.0*acoef[m][3]*t2 + 4.0*acoef[m][4]*t3 + 5.0*acoef[m][5]*t4; 
	float vel_ms = vel_s / 1000.0; // Chuyển sang xung / ms
 	// Gia tốc (xung / s^2)
	float acc_s2 =2.0 * acoef[m][2]+ 6.0 * acoef[m][3] * t+ 12.0 * acoef[m][4] * t2+ 20.0 * acoef[m][5] * t3;
	// đổi sang xung / ms^2
	s_curve_target_acc[m] = acc_s2 / 1e6;
	s_curve_target_pos[m] = pos;
	traj_vel[m] = vel_ms;
	s_curve_target_vel[m] = vel_ms; // Cập nhật target velocity từ quỹ đạo

}

/******************************************
 Position PID (outer) -> produce target velocity
 ******************************************/
void positionPID(int m) {
	long current_enc = (m==1)?enc1 : (m==2?enc2:enc3);
	float target_pos = s_curve_target_pos[m];
	float e_pos = target_pos - (float)current_enc;
	
	// ===== I TERM (ANTI-WINDUP NHẸ) =====
	const float KI_POS_DEADZONE = 3.0;
	if (fabs(e_pos) > KI_POS_DEADZONE)
		i_pos[m] += e_pos * (POS_INTERVAL_MS / 1000.0);
	else
		i_pos[m] *= 0.95;

	i_pos[m] = constrain(i_pos[m], -20000.0, 20000.0);

	// ===== D TERM =====
	float d_pos = (e_pos - p_pos[m]) / (POS_INTERVAL_MS / 1000.0);
	p_pos[m] = e_pos;

	float v_target;

	// ===== FIX GÓC NHỎ – KHỚP 2 =====
	if (m == 2 && fabs(e_pos) < 20.0) {   // ~10 độ
		float vmin = 0.8;
		v_target = Kp_pos[m] * e_pos;

		if (fabs(v_target) < vmin)
			v_target = copysign(vmin, v_target);
	}
	else {
		v_target = Kp_pos[m] * e_pos
				 + Ki_pos[m] * i_pos[m]
				 + Kd_pos[m] * d_pos;
	}

	// ===== GIỚI HẠN VẬN TỐC =====
	float vmax;
	if (m == 2 && s_curve_target_vel[m] < 0)
		vmax = MAX_VELOCITY * 0.2;
	else if (s_curve_target_vel[m] < 0)
		vmax = MAX_VELOCITY * 0.35;
	else
		vmax = MAX_VELOCITY;

	v_target = constrain(v_target, -vmax, vmax);

	pid_vel_cmd[m] = v_target;
}

/******************************************
 Velocity PID (inner) -> produce PWM
 ******************************************/
void velocityPID(int m) {
	// ===== 1. CURRENT VELOCITY (Vòng lặp trong 5ms) =====
	float raw_vel;
	if (m == 1) raw_vel = current_velocity1;
	else if (m == 2) raw_vel = current_velocity2;
	else raw_vel = current_velocity3;

	// ===== 2. LPF VELOCITY (Lọc nhiễu cho vận tốc đọc được) =====
	// Hệ số 0.7 cho M2 là hợp lý nhất.
	if (m == 1) vel_lpf[m] = 0.5 * vel_lpf[m] + 0.5 * raw_vel;
	else if (m == 3) vel_lpf[m] = 0.6 * vel_lpf[m] + 0.4 * raw_vel;
	else vel_lpf[m] = 0.7 * vel_lpf[m] + 0.3 * raw_vel;

	float current_vel = vel_lpf[m];
	float v_target = pid_vel_cmd[m]; // Vận tốc mục tiêu từ Vòng Position PID
	float e_vel = v_target - current_vel;
    float out = 0.0;
    
	// Lỗi vị trí cuối cùng (dùng cho các hiệu chỉnh gần đích)
	long enc = (m==1?enc1:(m==2?enc2:enc3));
	long posErr = final_target_pulse[m] - enc;

	// =================================================================
	// ===== 3. PID CORE (Bù sai số) =====
	// =================================================================
	
	// I TERM (Anti-Windup)
	const float KI_VEL_DEADZONE = 0.3; // Tăng nhẹ để I-term chỉ hoạt động khi sai số lớn hơn
	if (fabs(e_vel) > KI_VEL_DEADZONE)
		i_vel[m] += e_vel * (VEL_INTERVAL_MS / 1000.0);
	else
		i_vel[m] *= 0.9; // Giảm nhẹ khi ở Deadzone
	
	i_vel[m] = constrain(i_vel[m], -1000.0, 1000.0);

	// D TERM
	float d_vel = (e_vel - p_vel[m]) / (VEL_INTERVAL_MS / 1000.0);
	p_vel[m] = e_vel;

	// Tính toán PID
	float pid_out =
		  Kp_vel[m] * e_vel
		+ Ki_vel[m] * i_vel[m]
		+ Kd_vel[m] * d_vel;

	// =================================================================
	// ===== 4. FEEDFORWARD (Lực tiên đoán) =====
	// =================================================================
	float FF_v = Kff_v[m] * v_target;
	float FF_a = Kff_a[m] * s_curve_target_acc[m];

	// Giảm gia tốc FF khi đi xuống (để tránh phản ứng quá mức)
	if (v_target < 0) {
		float v_ratio = fabs(v_target) / MAX_VELOCITY;
		v_ratio = constrain(v_ratio, 0.0, 1.0);
		FF_a *= v_ratio * 0.3;
	}
    
	// Giảm nhẹ FF khi rất gần đích (tránh trượt)
	if (abs(posErr) < 8) {
		FF_v = 0;
		FF_a = 0;
	}

	// =================================================================
	// ===== 5. GRAVITY FF (Bù trọng lực) =====
	// =================================================================
	float grav = 0.0;
	if (m == 2 || m == 3) {
		float theta = joint_angle_rad(m);
		grav = Kgrav[m] * sin(theta);

		// Giảm Grav FF cho M3 khi M2 xoay nhanh (giả định M2 gây rung/nhiễu)
		if (m == 3) {
			float coupling = constrain(fabs(current_velocity2) / 2.0, 0.0, 0.8);
			grav *= (1.0 - coupling);
		}
        
        // Trọng lực luôn được cộng vào nếu nó chống lại trọng lực hoặc trừ đi nếu nó giúp trọng lực
		if (posErr < 0) {
            // Khi đi xuống, grav (dương) sẽ làm tăng tốc. Ta cần trừ nó ra.
            grav = -grav;
        }}


	// =================================================================
	// ===== 6. TỔNG OUTPUT TRƯỚC HIỆU CHỈNH DESCENT/SCALE =====
	// =================================================================
	out = pid_out + FF_v + FF_a + grav;
    
	
    // =================================================================
    // ===== 7. DESCENT / SCALE MODE (Hiệu chỉnh tùy biến) =====
    // =================================================================
    
    // **Hiệu chỉnh chung khi đi xuống (Descent)**
    if ((m == 2 || m == 3) && v_target < 0) {
        // Giảm hệ số PID/FF khi đi xuống để tránh phản ứng thái quá do trọng lực
        // Tỷ lệ này sẽ giúp motor chạy mượt mà hơn khi đi xuống
        out *= 0.7; // Giảm tổng tác động 30%
        
        // Giới hạn cứng cho Descent Mode
        float descent_limit = (m == 2) ? 80.0 : 120.0;
        out = constrain(out, -descent_limit, descent_limit);
    }
    
    // **Ma sát tĩnh (Cho M2)**
	// Áp dụng trước khi Scaling gần đích, nhưng sau khi tổng hợp PID+FF+Grav
	if (m == 2 && fabs(v_target) > 0.1 && fabs(v_target) < 1.5) { // Chỉ áp dụng khi motor bắt đầu hoặc đang chạy chậm
		out += copysign(22.0, v_target);
	}
	if (m == 3 && fabs(v_target) > 0.1 && fabs(v_target) < 1.2) {
    out += copysign(18.0, v_target);
}   
    // **Giảm phản ứng M3 khi M2 xoay nhanh**
	if (m == 3 && fabs(current_velocity2) > 1.5 && fabs(posErr) < 30) {
		out *= 0.5; // Giảm 50% tổng lực đẩy
	}
    
    // **Scaling gần đích (M2, M3)**
    if (m == 2 && abs(posErr) < 5) {
        float scale = constrain(abs(posErr) / 10.0, 0.4, 1.0);
        out *= scale;
    }
    if (m == 3 && abs(posErr) < 10) {
        float scale = constrain(abs(posErr) / 10.0, 0.3, 1.0);
        out *= scale;
    }
	// LPF cho PWM
	float filt;
    // Sử dụng alpha đã định nghĩa sẵn
	if (m == 3)
		filt = 0.65 * prev_out[m] + 0.35 * out;
	else
		filt = alpha * out + (1.0 - alpha) * prev_out[m];

	prev_out[m] = filt;
	filt = constrain(filt, -pwm_limit, pwm_limit);

	applyPWM(m, filt);
}

/******************************************
 apply PWM to motor m (1..3)
 ******************************************/
void applyPWM(int m, float pwm) {
	int ipwm = abs((int)pwm);
	if (ipwm > 255) ipwm = 255;

	if (pwm > 0) {
		if (m==1) fwd1(ipwm);
		else if (m==2) fwd2(ipwm);
		else fwd3(ipwm);
	}
	else if (pwm < 0) {
		if (m==1) rev1(ipwm);
		else if (m==2) rev2(ipwm);
		else rev3(ipwm);
	}
	else {
		if (m==1) stop1();
		else if (m==2) stop2();
		else stop3();
	}
}
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
void loop() {
	// parse serial incoming line (non-blocking)
	if (stringComplete) {
		inputString.trim();
		if (inputString.length() > 0) {
			if (inputString.startsWith("SET")) {
				inputString.replace("SET", "");
				inputString.trim();
				int firstSpace = inputString.indexOf(' ');
				int secondSpace = inputString.indexOf(' ', firstSpace + 1);
				if (firstSpace == -1 || secondSpace == -1) {
					Serial.println("SET format error: SET a b c (degrees)");
				} else {
					float a = inputString.substring(0, firstSpace).toFloat();
					float b = inputString.substring(firstSpace + 1, secondSpace).toFloat();
					float c = inputString.substring(secondSpace + 1).toFloat();
					
					update_encoder_readings(); 
					resetPIDState();
					pulse[1] = (long)(a * pulsesPerDegree1);
					pulse[2] = (long)(b * pulsesPerDegree2);
					pulse[3] = (long)(c * pulsesPerDegree3);
					
					final_target_pulse[1] = pulse[1];
					final_target_pulse[2] = pulse[2];
					final_target_pulse[3] = pulse[3];
					
					target_position[1] = (float)final_target_pulse[1];	
					target_position[2] = (float)final_target_pulse[2];
					target_position[3] = (float)final_target_pulse[3];

					start_position[1] = enc1;
					start_position[2] = enc2;
					start_position[3] = enc3;

					// Bắt đầu lập quỹ đạo cho tất cả motor
					plan_quintic_trajectory(1);
					plan_quintic_trajectory(2);
					plan_quintic_trajectory(3);
					//resetPIDState();
					motor_enabled = true;
					is_all_done=true;
					has_moved = false;

					
					for (int i=1;i<=3;i++) {
						i_pos[i] = 0.0;
						i_vel[i] = 0.0;
						nStable[i] = 0;
					}
					Serial.print("SET received (deg): ");
					Serial.print(a); Serial.print(", ");
					Serial.print(b); Serial.print(", ");
					Serial.println(c);
					Serial.print("SET received (pulse): ");
					Serial.print(final_target_pulse[1]); Serial.print(", ");
					Serial.print(final_target_pulse[2]); Serial.print(", ");
					Serial.println(final_target_pulse[3]);
				}
			}
			else if (inputString.equalsIgnoreCase("HOME")) {
				motor_enabled = true;
				Serial.println("Starting HOME...");
				startHomingSequence();
				Serial.println("HOME DONE");	
			}
			else if (inputString.equalsIgnoreCase("HUT")) {
				digitalWrite(ENA, HIGH);
				Serial.println("HUT DONE");
			}
			else if (inputString.equalsIgnoreCase("THA")) {
				digitalWrite(ENA, LOW);	
				Serial.println("THA DONE");
			}
			// clear input
			inputString = "";
		}
		stringComplete = false;
	}

	unsigned long now = millis();

	if (!motor_enabled) {
		brakeAll();
	} else {
		update_encoder_readings();

		// 1) inner loop - velocity PID @ 200Hz
		if (now - lastVel >= VEL_INTERVAL_MS) {
			calculate_current_velocity();	

			velocityPID(1);	
			velocityPID(2);
			velocityPID(3);
			
			lastVel = now;
		}

		// 2) outer loop - position PID @ 50Hz
		if (now - lastPos >= POS_INTERVAL_MS) {
			// Cập nhật quỹ đạo cho tất cả motor
			sample_trajectory(1);
			sample_trajectory(2);
			sample_trajectory(3);

			positionPID(1);
			positionPID(2);
			positionPID(3);

			lastPos = now;
		}
	
	// Kiểm tra đã di chuyển chưa
	if (!has_moved) {
		if (abs(enc1 - start_position[1]) > 5 ||
			abs(enc2 - start_position[2]) > 5 ||
			abs(enc3 - start_position[3]) > 5) {
			has_moved = true;
		}
	}

	// ================= DONE CHECK =================
	if (is_all_done) {

		bool traj_done =
			!traj_active[1] &&
			!traj_active[2] &&
			!traj_active[3];

		// -------- Joint 1 --------
		long e1 = final_target_pulse[1] - enc1;
		bool pos_ok1 = abs(e1) <= allowError1;
		bool vel_ok1 = fabs(current_velocity1) < 0.2;
		if (pos_ok1 && vel_ok1) nStable[1]++;
		else nStable[1] = 0;

		// -------- Joint 2 --------
		long e2 = final_target_pulse[2] - enc2;
		bool pos_ok2 = abs(e2) <= 7;	
		bool vel_ok2 = fabs(current_velocity2) < 0.2;
		if (pos_ok2 && vel_ok2) nStable[2]++;
		else nStable[2] = 0;

		// -------- Joint 3 --------
		long e3 = final_target_pulse[3] - enc3;
		bool pos_ok3 = (abs(e3) <= 6);
		bool vel_ok3 = fabs(current_velocity3) < 0.1;
		if (pos_ok3 && vel_ok3) nStable[3]++;
		else nStable[3] = 0;

		if (traj_done &&
			nStable[1] >= STABLE_COUNT &&
			nStable[2] >= STABLE_COUNT &&
			nStable[3] >= STABLE_COUNT &&
			has_moved) {

			Serial.println("ALL DONE");
			Serial.println("DONE");
			is_all_done = false;
			//resetPIDState(); // Reset PID khi hoàn tất để chuẩn bị cho lệnh tiếp theo
		}
	}

	} // end motor_enabled branch
	//update_encoder_readings();
  //printlog();
}

/******************************************
 Debug Log
 ******************************************/
void printlog()
{
	static unsigned long tlog = 0;
	if (millis() - tlog > 200) {
		Serial.print("Taget: ");
		Serial.print(final_target_pulse[1]); Serial.print(", ");
		Serial.print(final_target_pulse[2]); Serial.print(", ");
		Serial.println(final_target_pulse[3]);
		Serial.print("| Enc: ");
		Serial.print(enc1); Serial.print(", ");
		Serial.print(enc2); Serial.print(", ");
		Serial.println(enc3);
		tlog = millis();
	}
}

/******************************************
 serialEvent() - collect line
 ******************************************/
void serialEvent() {
	while (Serial.available()) {
		char inChar = (char)Serial.read();
		if (inChar == '\n' || inChar == '\r') {
			stringComplete = true;
		} else {
			inputString += inChar;
		}
	}
}

// Hàm hỗ trợ tính góc khớp theo radian (cho Grav FF)
float joint_angle_rad(int m) {
	if (m == 2) return enc2 / pulsesPerDegree2 * DEG_TO_RAD;
	if (m == 3) return enc3 / pulsesPerDegree3 * DEG_TO_RAD;
	return 0;
}

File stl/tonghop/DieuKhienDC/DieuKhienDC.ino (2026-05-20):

const int IN1 = 4;
const int IN2 = 5;
const int encoderA = 2;  // Pha A - có ngắt
const int encoderB = 8;  // Pha B - đọc trong ISR

volatile long encoderCount = 0;
int targetPulses = 0;

float pulsesPerRevolution = 1848.0; // 11 xung * tỉ số truyền 18
float pulsesPerDegree = pulsesPerRevolution / 360.0;

void setup() {
  pinMode(IN1, OUTPUT);
  pinMode(IN2, OUTPUT);
  pinMode(encoderA, INPUT_PULLUP);
  pinMode(encoderB, INPUT_PULLUP);
  
  attachInterrupt(digitalPinToInterrupt(encoderA), encoderISR, RISING);
  
  Serial.begin(9600);
  Serial.println("Nhap goc muon quay (do):");
}

void loop() {
  if (Serial.available() > 0) {
    float deg = Serial.parseFloat();
    targetPulses = abs(deg * pulsesPerDegree);
    encoderCount = 0;
    
    Serial.print("Quay ");
    Serial.print(deg);
    Serial.println(" do...");

    if (deg > 0) {
      quayThuan();
    } else {
      quayNguoc();
    }

    // Chờ đạt số xung mục tiêu
    while (abs(encoderCount) < targetPulses);

    // Dừng motor
    dungMotor();

    Serial.println("Hoan thanh!");
    Serial.println("Nhap goc moi:");
  }
}

// --- Ngắt đếm xung encoder ---
void encoderISR() {
  int b = digitalRead(encoderB); // đọc pha B để xác định chiều
  if (b == HIGH)
    encoderCount++;
  else
    encoderCount--;
}

// --- Điều khiển motor ---
void quayThuan() {
  digitalWrite(IN1, HIGH);
  digitalWrite(IN2, LOW);
}

void quayNguoc() {
  digitalWrite(IN1, LOW);
  digitalWrite(IN2, HIGH);
}

void dungMotor() {
  digitalWrite(IN1, LOW);
  digitalWrite(IN2, LOW);
}

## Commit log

2025-10-30 code kinematic cua Tmai đã chạy đang lỗi Py
2025-10-30 đã fix lỗi cho ra 2 giá trị Py ở w1
2026-05-20 toàn bộ dự án DR3 robot 3dof hút bằng nam châm
    [25mm DC Motor.stl, Arm 2.SLDPRT, Arm 2.STL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]
2026-05-20 chinh sửa lại thư mục stl
    [25mm DC Motor.stl, Arm 2.SLDPRT, Arm 2.STL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]
2026-05-20 bổ sung readme
